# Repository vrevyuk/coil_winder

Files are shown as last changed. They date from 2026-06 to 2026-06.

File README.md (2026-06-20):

# Coil winder

A turn counter for winding air-core inductors with a **Xiaomi electric screwdriver**.
A 3D-printed reduction gear (1/2 or 1/3) keeps the screwdriver from overheating, an
optical sensor counts turns on the driven axle, and an **RP2040-Zero** shows the live
coil-turn count on a **TM1637** 7-segment display.

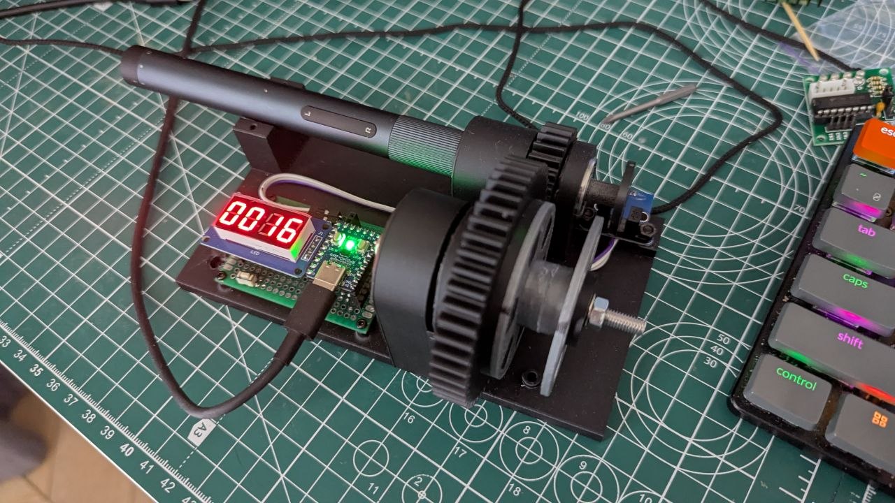
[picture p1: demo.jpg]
Coil winder build: screwdriver, reduction gear, optical sensor, and RP2040-Zero driving a TM1637 display


## Hardware

- **RP2040-Zero** — controller and power hub (USB-C 5 V)
- **Optical encoder/sensor** with comparator amp (slotted disk)
- **TM1637** 4-digit 7-segment display (red)
- Reduction gear between the screwdriver and the coil (3D printed)
- Momentary push button (count reset)

The 3D model (reduction gear, sensor disk, mounts) is in
[`coil-winder.f3d`](coil-winder.f3d) — an Autodesk Fusion 360 archive; open it in
Fusion 360 to edit or to export STLs for printing.

### Wiring

| RP2040-Zero | Connects to | Notes |
|---|---|---|
| 5V (USB) | TM1637 VCC | Display runs from 5 V for full brightness |
| GP0 | TM1637 CLK | Clock (MCU → display) |
| GP1 | TM1637 DIO | Data (MCU ↔ display) |
| 3V3 | Optical sensor VCC | Powers the sensor so OUT swings 0–3.3 V |
| GP2 | Optical sensor OUT | Turn pulses (edge interrupt) |
| GP3 | Reset button → GND | Internal pull-up, active-low |
| GP16 | Onboard WS2812 RGB LED | Green at idle, purple flash per counted turn |
| GND | All device grounds | Common ground |

> **3.3 V only:** RP2040 GPIO are not 5 V tolerant — power the sensor from **3V3**
> (or add a divider/level shifter on OUT). See [`spec.md`](spec.md) for the full
> schematic and voltage notes.

## Firmware

MicroPython, in [`firmware/`](firmware/):

- **`main.py`** — counts coil turns and drives the display. A reset button on GP3
  zeros the count.
- **`test_count.py`** — calibration helper for `PULSES_PER_REV`.
- **`tm1637.py`** — minimal 4-digit TM1637 driver.

### Anti-chatter counting

The sensor's comparator has no hysteresis, so as a slot edge slowly crosses the beam
its output **chatters** — turned slowly, one slot reads as several counts; turned fast
it reads correctly. The firmware fixes this by counting **one pulse per slot**: a
rising edge is counted only while *armed*, then it disarms and re-arms only after the
line has settled cleanly LOW (driven by a hardware timer). The result is
speed-independent — verified at 40 pulses/coil-turn for both slow and fast winding.

An optional hardware **RC low-pass** on the OUT line (start with R = 1 kΩ, C = 100 nF)
cleans the signal at the source; see the sensor signal note in [`spec.md`](spec.md).

### Key tunables (top of `main.py`)

| Setting | Meaning |
|---|---|
| `PULSES_PER_REV` | Sensor pulses per coil turn (40 = 20-slot disk × 2:1 gear) |
| `COIL_TURNS_NUM/DEN` | Extra gear ratio (1/1 — gearing already folded into the rate) |
| `REARM_US` | Line must be settled LOW this long before the next slot counts |
| `REARM_SAMPLE_HZ`  | Re-arm timer sample rate |
| `RESET_DEBOUNCE_US`| Reset-button debounce |

## Install

1. Flash the [MicroPython UF2](https://micropython.org/download/RPI_PICO/) to the
   RP2040-Zero (hold BOOTSEL, plug in USB, copy the UF2).
2. Copy the firmware to the board, e.g. with [`mpremote`](https://docs.micropython.org/en/latest/reference/mpremote.html):

   ```sh
   mpremote connect /dev/ttyACM0 fs cp firmware/main.py :main.py
   mpremote connect /dev/ttyACM0 fs cp firmware/tm1637.py :tm1637.py
   mpremote connect /dev/ttyACM0 reset
   ```

   `main.py` runs on boot.

## Calibrate

If you change the disk or gearing, re-measure `PULSES_PER_REV`:

```sh
mpremote connect /dev/ttyACM0 run firmware/test_count.py
```

Turn the coil a known number of full turns, then divide the reported count by that
number and put the result in `PULSES_PER_REV`.

## Usage

1. Power the RP2040-Zero over USB-C — the display shows `0`, RGB LED green.
2. Wind the coil; the display tracks turns and the LED flashes purple per turn.
3. Press the reset button to zero the count.

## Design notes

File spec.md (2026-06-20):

# Coil winder

Coil winder that use electric screw-driver Xiaomi to wind air inductors. To prevent over heating of screw-driver I plan use 3d printed gear.
Rate can be 1/2 or 1/3. Use an optical sensor to counting turns on the folled axe. Supply for display and optical sensor provides by usb-c 5 volt of rp2040.

## Parts
- RP2040-Zero
- Optical encoder/sensor with amp
- 7 segments display based on TM1637 (red, with full column)

## Schematic

The RP2040-Zero is the controller and power hub. It is powered from USB-C (5 V),
reads the optical sensor to count turns, and drives the TM1637 display to show the
count.

```
                          USB-C 5V
                             │
                  ┌──────────┴───────────┐
                  │     RP2040-Zero      │
                  │                      │
   ┌──── 3V3  ────┤ 3V3              5V  ├──── 5V ───┐
   │              │                      │           │
   │   ┌─── GND ──┤ GND             GND  ├─── GND ─┐ │
   │   │          │                      │         │ │
   │   │   CLK ◄──┤ GP0             GP1  ├──► DIO  │ │
   │   │          │                      │         │ │
   │   │   OUT ──►┤ GP2             GP3  ├──┐      │ │
   │   │          └──────────────────────┘  │      │ │
   │   │                                     │      │ │
   │   │            Reset button             │      │ │
   │   │             ┌───o o───┐             │      │ │
   │   │       GP3 ──┤         ├── GND       │      │ │
   │   │             └─────────┘   │         │      │ │
   │   │       (button bridges GP3 to GND)   │      │ │
   │   │                                            │ │
   │   │     ┌───────────────────────┐              │ │
   │   │     │  Optical sensor + amp │              │ │
   └───┼─────┤ VCC                   │              │ │
       └─────┤ GND               OUT ├──► (to GP2)  │ │
             └───────────────────────┘              │ │
                                                    │ │
             ┌───────────────────────┐              │ │
             │   TM1637 7-seg disp.  │              │ │
             │ VCC               CLK ├◄── (GP0)     │ │
        ┌────┤ GND               DIO ├◄── (GP1)     │ │
        │    └──┬────────────────────┘              │ │
        │       └── VCC ◄─────────────────── 5V ────┘ │
        └────────── GND ◄─────────────────────────────┘
```

### Pin mapping

| RP2040-Zero | Connects to | Notes |
|---|---|---|
| 5V (USB) | TM1637 VCC | Display runs from 5 V for full brightness |
| GP0 | TM1637 CLK | Clock line (MCU → display) |
| GP1 | TM1637 DIO | Data line (MCU ↔ display) |
| 3V3 | Optical sensor VCC | See voltage note below |
| GP2 | Optical sensor OUT | Turn pulses; use edge interrupt to count |
| GP3 | Reset button | Other side to GND; internal pull-up, active-low |
| GP16 | Onboard WS2812 RGB LED | On-board addressable LED; lit green at startup |
| GND | TM1637 GND, sensor GND, button | Common ground for all devices  |

### Voltage note

RP2040 GPIO are **3.3 V tolerant only** — do not feed them a 5 V signal. Power the
optical sensor/amp board from the **3V3** rail so its output swings 0–3.3 V and can
drive GP2 directly. If the sensor must run at 5 V, add a divider or level shifter on
the OUT line before GP2.

The TM1637 is driven by the MCU (MCU outputs on CLK/DIO), so the 3.3 V logic levels
are fine even though the display module itself is powered at 5 V.

### Sensor signal note (RC filter)

The optical sensor's comparator has no hysteresis, so as a slot edge slowly crosses
the beam its OUT line **chatters** (oscillates near the threshold). Turned slowly,
this makes one slot read as several counts; turned fast it reads correctly. The
firmware rejects the chatter in software (see below), but a hardware RC low-pass on
the OUT line cleans the signal at the source and is recommended insurance for fast
winding:

```
   sensor OUT ──[ R ]──┬── GP2
                       │
                     [ C ]
                       │
                      GND
```

- Start with **R = 1 kΩ, C = 100 nF** → time constant τ = R·C = 100 µs, −3 dB ≈ 1.6 kHz.
  This smooths the sub-300 µs chatter bursts while passing the real slot rate
  (~tens of Hz when winding) untouched.
- Keep τ well **below** the real slot period at top speed:
  `slot_period_us = 60e6 / (max_coil_rpm * PULSES_PER_REV)`. With 40 pulses/coil-turn
  even 1500 coil-rpm gives a 1000 µs slot period, comfortably above τ = 100 µs.
- If chatter persists, increase C (e.g. 220 nF) or R, or feed the filtered line through
  a Schmitt-trigger input (e.g. 74HC14) for a clean square edge. Adjusting the sensor
  board's threshold potentiometer also helps.

## Firmware

MicroPython, in `firmware/`:

- `main.py` — counts coil turns from GP2 and shows the live count on the TM1637.
  A reset button on GP3 zeros the count. To stay accurate at any speed despite the
  comparator chatter (see the sensor signal note above), it counts **one pulse per
  slot**: a rising edge is counted only while "armed", then it disarms and re-arms
  only after the line has settled LOW for `REARM_US` (re-arm is driven by a hardware
  timer at `REARM_SAMPLE_HZ`). Tunables at the top: `PULSES_PER_REV` (sensor pulses
  per coil turn — 40 here, = 20-slot disk × the 2:1 gear, calibrated directly against
  the coil so the gear ratio is folded in), `COIL_TURNS_NUM`/`COIL_TURNS_DEN` (left
  1/1), `REARM_US`, `REARM_SAMPLE_HZ`, `RESET_DEBOUNCE_US`.
- `test_count.py` — anti-chatter counter used to (re)calibrate `PULSES_PER_REV`:
  turn the coil a known number of turns and divide the reported count.
- `tm1637.py` — minimal 4-digit TM1637 display driver.

Flash the MicroPython UF2 to the RP2040-Zero, then copy both files to the board
(e.g. with `mpremote` or Thonny). `main.py` runs on boot.

## 3D printer files

- [`coil-winder.f3d`](coil-winder.f3d) — Autodesk Fusion 360 archive with the full
  3D model (reduction gear, sensor disk, mounts). Open in Fusion 360 to edit or to
  export STLs for printing.

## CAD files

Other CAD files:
coil-winder.f3d

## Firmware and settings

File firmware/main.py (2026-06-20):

"""Coil winder firmware (RP2040-Zero, MicroPython).

Counts turns from the optical sensor and shows the live count on a TM1637
7-segment display. Pin assignments match spec.md / the schematic.

Counting method (anti-chatter):
    The optical comparator has no hysteresis, so as a slot edge slowly crosses
    the beam its output CHATTERS (oscillates) near the threshold. A plain per-
    edge counter therefore over-counts at slow speed (1 turn read as 2-4) while
    reading correctly when turned fast. To be speed-independent we count ONE
    pulse per slot: a rising edge is counted only while 'armed', then we disarm
    and re-arm only after the line has settled cleanly LOW for REARM_US. Chatter
    never holds a sustained low, so it is ignored. Re-arming is done from a
    hardware timer so it stays accurate even while the display is being written.
    (A hardware fix -- adding hysteresis via the sensor's threshold pot, an RC
    filter, or a 74HC14 Schmitt trigger on OUT -- would let a plain counter work
    too, and is worth doing if you ever wind fast enough to drop counts.)

Wiring (RP2040-Zero):
    GP0  -> TM1637 CLK
    GP1  -> TM1637 DIO
    GP2  -> Optical sensor OUT (pulse per slot)
    GP3  -> Reset button (other side to GND)
    3V3  -> sensor VCC      5V -> TM1637 VCC      GND -> common
"""

from machine import Pin, Timer
from neopixel import NeoPixel
from time import ticks_us, ticks_diff, ticks_ms, ticks_add, sleep_ms
import tm1637

# ---------------------------------------------------------------------------
# Configuration
# ---------------------------------------------------------------------------
PIN_CLK = 0          # TM1637 clock
PIN_DIO = 1          # TM1637 data
PIN_SENSOR = 2       # optical sensor output
PIN_RESET = 3        # reset button to GND
PIN_RGB = 16         # onboard WS2812 RGB LED (RP2040-Zero)

# Colors for the RGB LED, as (R, G, B), 0-255 each. Kept dim so the single
# onboard LED isn't blinding.
RGB_START_COLOR = (0, 40, 0)    # green: shown at startup / idle between turns
RGB_TURN_COLOR = (40, 0, 40)    # purple: flashed briefly on each counted turn

# How long the purple flash stays on per counted turn, in milliseconds.
RGB_BLINK_MS = 60

# Sensor pulses per ONE full turn of the COIL (output) axle. Measured on
# 2026-06-20 with the anti-chatter counter (firmware/test_count.py): 10 slow
# turns -> 400, 10 fast turns -> 401, i.e. 40 pulses/coil-turn. That matches the
# hardware: a 20-slot disk on the screwdriver axle x the 2:1 (50/25) gear = 40.
# Because it is measured against the coil, the gear ratio is already folded in.
# Re-calibrate with firmware/test_count.py if the disk or gearing changes.
PULSES_PER_REV = 40

# Gear ratio is already baked into PULSES_PER_REV above (calibrated directly
# against the coil), so this stays 1/1.
COIL_TURNS_NUM = 1
COIL_TURNS_DEN = 1

# Anti-chatter re-arm: after a slot is counted, the next slot is only counted
# once the sensor line has been settled LOW for at least this long. It must be
# LONGER than the comparator's chatter bursts (<300 us observed) and SHORTER
# than the real low-gap between slots at top winding speed:
#   min_low_us ~= 60e6 / (max_coil_rpm * PULSES_PER_REV) / 2
# At 500 us this is comfortable for any hand/screwdriver winding speed here.
REARM_US = 500

# Rate at which the timer samples the line to re-arm, in Hz (2000 Hz = 500 us).
REARM_SAMPLE_HZ = 2000

# Debounce window for the reset button press, in microseconds.
RESET_DEBOUNCE_US = 50000

# ---------------------------------------------------------------------------
# State
# ---------------------------------------------------------------------------
_pulse_count = 0           # counted slots since reset
_armed = True              # True when ready to count the next slot's rising edge
_last_edge_us = 0          # timestamp of the most recent sensor transition
_last_reset_us = 0         # timestamp of last accepted reset press
_sensor = None             # Pin object, shared with the re-arm timer ISR


def _on_edge(pin):
    """ISR (both edges): count one slot per armed rising edge, then disarm.

    Every transition refreshes _last_edge_us so the timer can tell when the
    line has truly settled. Chatter edges arrive while disarmed and are ignored.
    """
    global _pulse_count, _armed, _last_edge_us
    _last_edge_us = ticks_us()
    if _armed and pin.value():          # armed + rising == start of a real slot
        _pulse_count += 1
        _armed = False


def _rearm_tick(t):
    """Timer ISR: re-arm once the line has been settled LOW past REARM_US."""
    global _armed
    if (not _armed and _sensor.value() == 0
            and ticks_diff(ticks_us(), _last_edge_us) > REARM_US):
        _armed = True


def turns():
    """Coil turns derived from counted slots, with the gear ratio folded in.

    coil_turns = slots / PULSES_PER_REV * (COIL_TURNS_NUM / COIL_TURNS_DEN)

    Done as integer math so the displayed count never drifts from rounding.
    """
    return (_pulse_count * COIL_TURNS_NUM) // (PULSES_PER_REV * COIL_TURNS_DEN)


def reset(pin=None):
    """Zero the counter. Usable as a button ISR or called directly."""
    global _pulse_count, _last_reset_us, _armed
    if pin is not None:                      # debounce button presses
        now = ticks_us()
        if ticks_diff(now, _last_reset_us) < RESET_DEBOUNCE_US:
            return
        _last_reset_us = now
    _pulse_count = 0
    _armed = True


def main():
    global _sensor

    # Light the onboard RGB LED green to signal the firmware is up.
    rgb = NeoPixel(Pin(PIN_RGB), 1)
    rgb[0] = RGB_START_COLOR
    rgb.write()

    display = tm1637.TM1637(clk=Pin(PIN_CLK), dio=Pin(PIN_DIO))
    display.brightness(5)

    _sensor = Pin(PIN_SENSOR, Pin.IN, Pin.PULL_UP)
    _sensor.irq(trigger=Pin.IRQ_RISING | Pin.IRQ_FALLING, handler=_on_edge)

    button = Pin(PIN_RESET, Pin.IN, Pin.PULL_UP)
    button.irq(trigger=Pin.IRQ_FALLING, handler=reset)

    # Drive re-arm from a hardware timer so counting stays accurate even while
    # the main loop is busy bit-banging the display.
    Timer(freq=REARM_SAMPLE_HZ, mode=Timer.PERIODIC, callback=_rearm_tick)

    last_shown = -1
    blink_off_at = 0       # when to revert the purple flash to green
    blinking = False
    while True:
        count = turns()
        if count != last_shown:
            display.number(count % 10000)   # display is 4 digits
            last_shown = count
            # Flash purple to mark the new turn; revert to green later.
            rgb[0] = RGB_TURN_COLOR
            rgb.write()
            blinking = True
            blink_off_at = ticks_add(ticks_ms(), RGB_BLINK_MS)
        elif blinking and ticks_diff(ticks_ms(), blink_off_at) >= 0:
            rgb[0] = RGB_START_COLOR
            rgb.write()
            blinking = False
        sleep_ms(10)


if __name__ == "__main__":
    main()

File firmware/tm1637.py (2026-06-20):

"""Minimal TM1637 4-digit 7-segment driver for MicroPython.

Subset of the well-known mcauser/micropython-tm1637 driver (MIT) covering
exactly what the coil winder needs: brightness, integer display, and the
column/colon segment. Drop-in: place next to main.py on the RP2040.
"""

from machine import Pin
from time import sleep_us

TM1637_CMD1 = const(0x40)   # data command: auto address increment
TM1637_CMD2 = const(0xC0)   # address command: start at digit 0
TM1637_CMD3 = const(0x80)   # display control command base
TM1637_DSP_ON = const(0x08) # display on bit

# Segment maps for 0-9 (bit order: .GFEDCBA)
_SEGMENTS = bytearray(
    b'\x3F\x06\x5B\x4F\x66\x6D\x7D\x07\x7F\x6F'
)


class TM1637:
    def __init__(self, clk, dio, brightness=7):
        self.clk = clk
        self.dio = dio
        self._brightness = brightness & 0x07
        self.clk.init(Pin.OUT, value=0)
        self.dio.init(Pin.OUT, value=0)
        self._write_data_cmd()
        self._write_dsp_ctrl()

    # --- low level ---------------------------------------------------------
    def _start(self):
        self.dio(0)
        self.clk(0)

    def _stop(self):
        self.dio(0)
        self.clk(1)
        self.dio(1)

    def _write_byte(self, b):
        for _ in range(8):
            self.dio(b & 1)
            sleep_us(1)
            self.clk(1)
            sleep_us(1)
            self.clk(0)
            b >>= 1
        # ack
        self.clk(0)
        sleep_us(1)
        self.clk(1)
        sleep_us(1)
        self.clk(0)

    def _write_data_cmd(self):
        self._start()
        self._write_byte(TM1637_CMD1)
        self._stop()

    def _write_dsp_ctrl(self):
        self._start()
        self._write_byte(TM1637_CMD3 | TM1637_DSP_ON | self._brightness)
        self._stop()

    # --- public API --------------------------------------------------------
    def brightness(self, val):
        self._brightness = max(0, min(7, val))
        self._write_data_cmd()
        self._write_dsp_ctrl()

    def write(self, segments, pos=0):
        self._write_data_cmd()
        self._start()
        self._write_byte(TM1637_CMD2 | (pos & 0x03))
        for seg in segments:
            self._write_byte(seg)
        self._stop()
        self._write_dsp_ctrl()

    def number(self, num, colon=False):
        """Display an integer right-aligned across the 4 digits."""
        num = max(0, min(9999, int(num)))
        digits = bytearray(4)
        for i in range(3, -1, -1):
            digits[i] = _SEGMENTS[num % 10]
            num //= 10
        if colon:
            digits[1] |= 0x80   # column/colon bit on second digit
        self.write(digits)

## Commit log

2026-06-20 Coil winder firmware with anti-chatter turn counting
    Count one pulse per slot via a settle-low scheme (rising-edge IRQ to count,
    2 kHz timer to re-arm only after the line settles LOW), making the coil-turn
    count speed-independent despite the optical comparator's edge chatter.
    Calibrated to 40 pulses/coil-turn (20-slot disk x 2:1 gear). Adds test_count.py
    calibrator and an RC-filter hardware note in spec.md.
2026-06-20 Add Fusion 360 3D model
    [coil-winder.f3d]
